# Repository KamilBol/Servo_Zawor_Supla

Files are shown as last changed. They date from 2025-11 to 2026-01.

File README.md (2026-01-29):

# Servo_Zawor_Supla (Wemos Edition)
### Sterownik zaworu C.O. na Wemos D1 Mini + SG90
**Autor:** Kamil Ból ("Bólu")

Projekt sterownika do zaworu kulowego (lub innego elementu C.O.), opartego na serwomechanizmie modelarskim (np. SG90) i mikrokontrolerze Wemos D1 Mini. Układ działa jako element wykonawczy dla systemu SUPLA (lub innej automatyki), reagując na impuls sterujący.

### 🔥 Główne Funkcje (Bólu Soft v3.0):
* **Sterowanie Mikrosekundami:** Pełna płynność i precyzja dla serw SG90/MG90.
* **Ghost Buster:** Algorytm odszumiania pinów (działa stabilnie bez zewnętrznych rezystorów!).
* **Pamięć EEPROM:** Po zaniku prądu sterownik pamięta, gdzie skończył. Zero szarpania przy starcie.
* **Safety Mode:** Jeśli czujnik (kontaktron) ulegnie awarii, system to wykryje i po 10 próbach zresetuje się, zamiast niszczyć zawór.
* **Tryb Serwisowy:** Możliwość kalibracji kątów i odwracania logiki przyciskami - bez podłączania komputera!

---

### 🛠️ Hardware (Co potrzebujesz)
1.  **Wemos D1 Mini** (ESP8266)
2.  **Serwo SG90** (lub MG996R - wymaga zmiany czasów w kodzie)
3.  **Kontaktron** (Czujnik otwarcia/zamknięcia)
4.  **Drugi moduł Supla** (jako wyzwalacz)
5.  Zasilacz 5V (stabilny!)

---

### 🔌 Pinout (Podłączenie)
Szczegółowy schemat znajdziesz w folderze `/doc`.

| PIN Wemos | Funkcja | Opis |
| :--- | :--- | :--- |
| **D1 (GPIO 5)** | **SERWO** | Sygnał PWM (Żółty/Pomarańczowy kabel) |
| **D2 (GPIO 4)** | **TRIGGER** | Impuls 3.3V (HI) z Supli uruchamia ruch |
| **D5 (GPIO 14)** | **CZUJNIK** | Kontaktron (HI 3.3V = Zamknięty) |
| **D4 (GPIO 2)** | **LED** | Wbudowana dioda sygnalizacyjna |
| **D6 (GPIO 12)** | *Serwis (-)* | Zmniejszanie kąta otwarcia |
| **D7 (GPIO 13)** | *Serwis (+)* | Zwiększanie kąta otwarcia |
| **D0 (GPIO 16)** | *Serwis (L)* | Odwracanie logiki czujnika (trzymać 5s) |

---

### 🚀 Jak to działa?
1.  Wemos czeka na impuls **3.3V (HI)** na pinie **D2**.
2.  Po otrzymaniu impulsu sprawdza stan czujnika na **D5**.
3.  Jeśli czujnik pokazuje "Zamknięty" -> Serwo otwiera zawór.
4.  Jeśli czujnik pokazuje "Otwarty" -> Serwo zamyka zawór.
5.  Ruch trwa 5 sekund (płynny start i stop).
6.  Pozycja zapisywana jest w pamięci stałej.

---

### 📜 Licencja
Róbta co chceta (MIT). Kod jest dla ludzi.
https://github.com/KamilBol/Servo_Zawor_Supla/blob/main/3D/Zrzut%20ekranu%202026-01-29%20003321.png?raw=true

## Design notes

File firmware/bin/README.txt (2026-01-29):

===================================  INSTRUKCJA FLASHOWANIA (.BIN)  ======================================
Uruchom ESP8266 Download Tool -> Developer Mode -> ESP8266.

SEKCJA "SPIDownload": [X] Zaznacz "ptaszka" przy ścieżce pliku. [...] Wybierz plik: STEROWNIK_ZAWORU.ino.bin [@] Adres wpisz: 0x00000

PARAMETRY (Wemos D1 Mini):

Crystal Freq: 26M

SPI SPEED: 40MHz

SPI MODE: DIO <-- WAŻNE!

FLASH SIZE: 32Mbit

PODŁĄCZENIE:

COM: Wybierz swój port.

BAUD: 921600 (lub 460800).

AKCJA: Kliknij START. Jak zobaczysz "FINISH", odłącz i podłącz zasilanie. Gotowe. 
=========================================================================

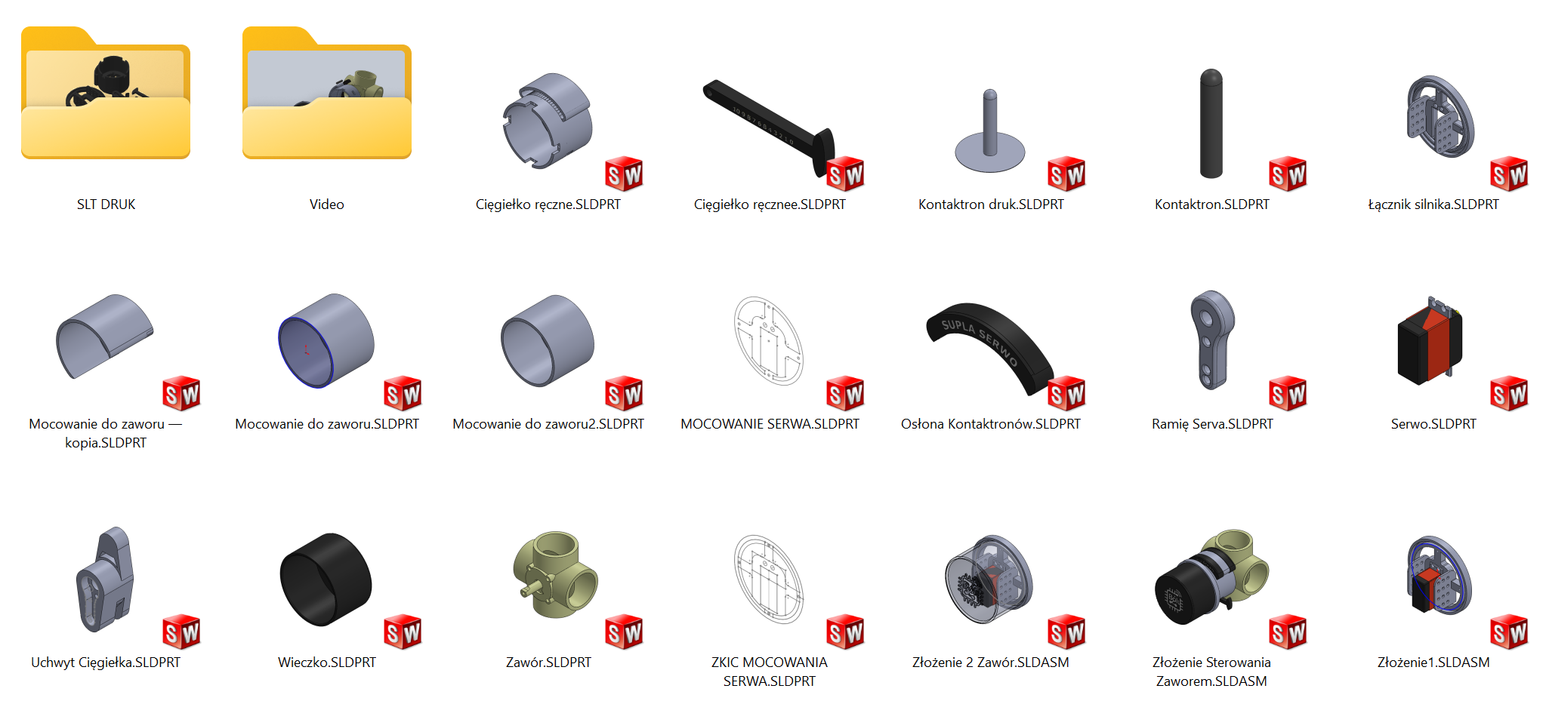
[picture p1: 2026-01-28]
3D/Zrzut ekranu 2026-01-29 003321.png

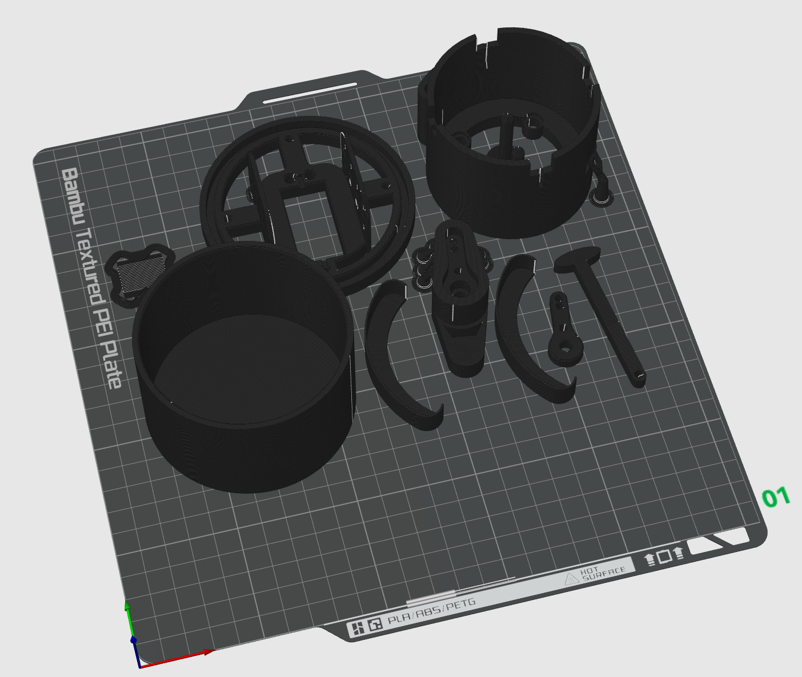
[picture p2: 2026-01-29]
3D/Zrzut ekranu 2026-01-29 011720.png

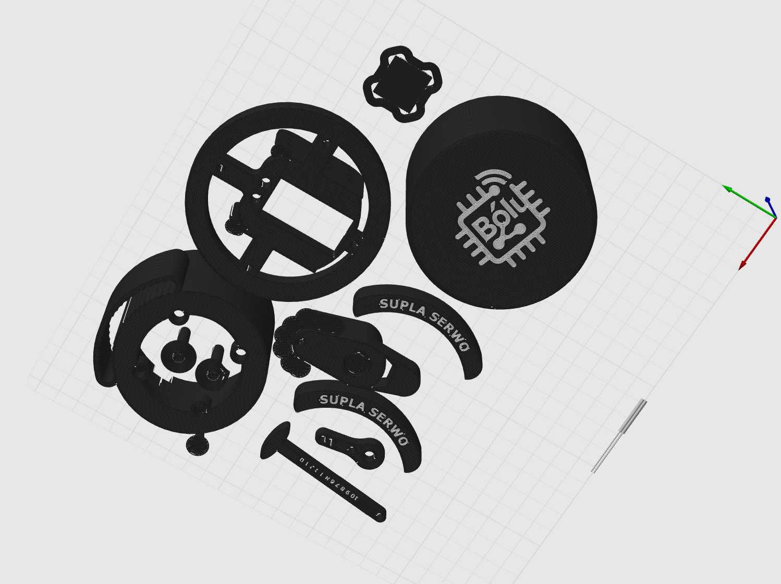
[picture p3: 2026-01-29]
3D/Zrzut ekranu 2026-01-29 011803.png

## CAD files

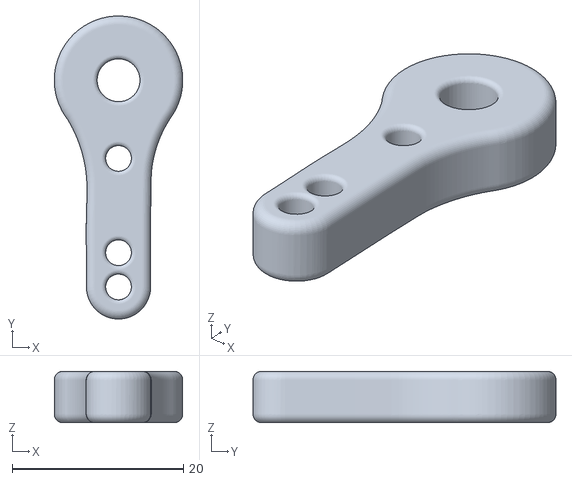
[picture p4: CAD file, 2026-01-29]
3D/7 Ramię Serva.STL
15.0 x 35.4 x 6.00

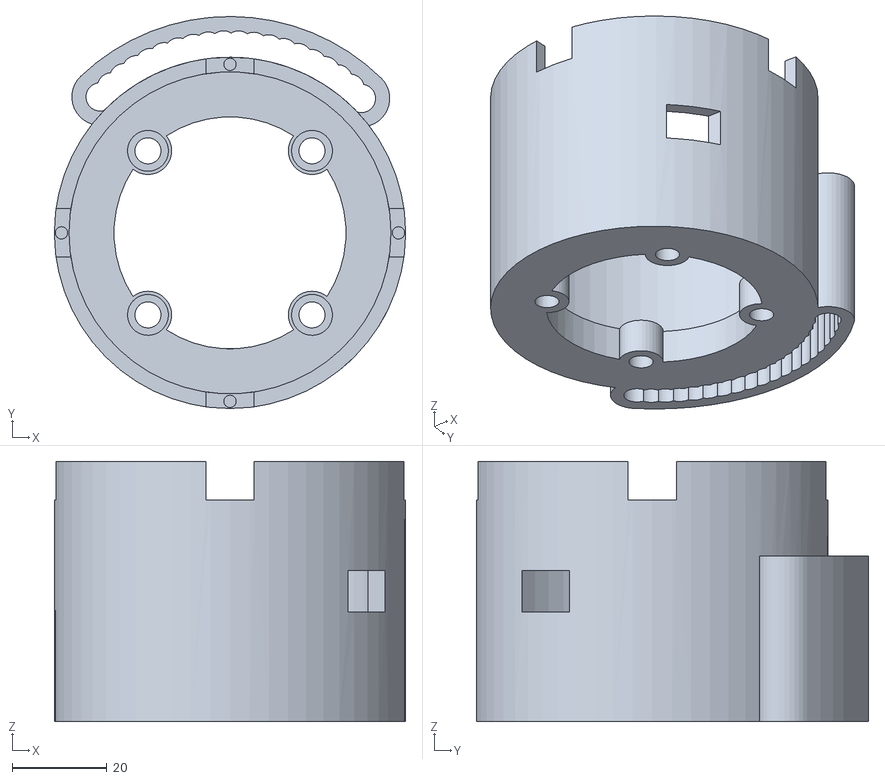
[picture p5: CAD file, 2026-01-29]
3D/1 Cięgiełko ręczne.STL
74.2 x 82.8 x 55.0

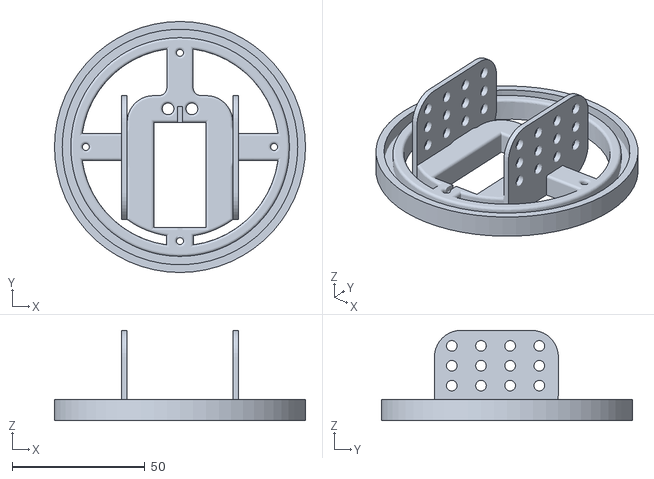
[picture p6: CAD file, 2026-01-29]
3D/6 Łącznik silnika.STL
94.6 x 94.6 x 34.0

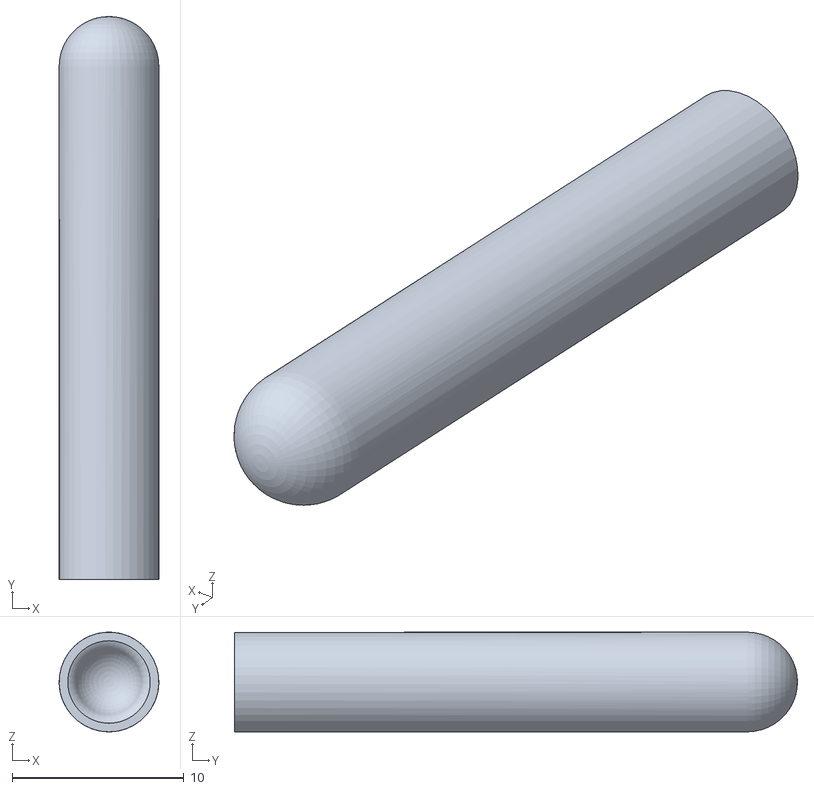
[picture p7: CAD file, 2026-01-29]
3D/4 Kontaktron X2 DRUKINIJ.STL
5.80 x 32.7 x 5.80

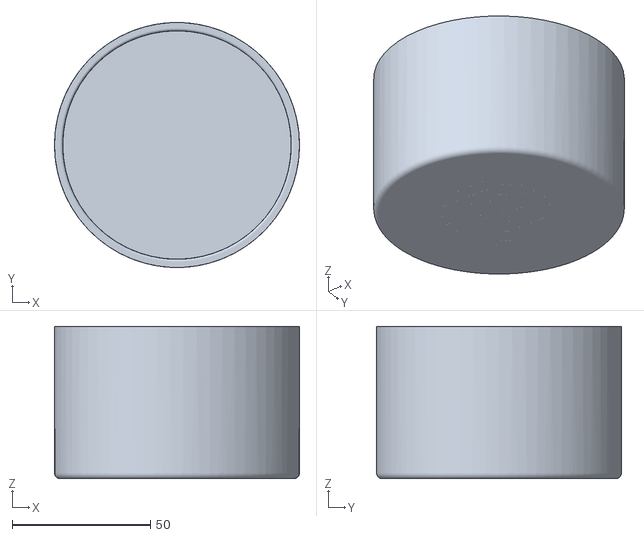
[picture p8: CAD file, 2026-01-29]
3D/8 Wieczko.STL
88.5 x 88.4 x 55.0

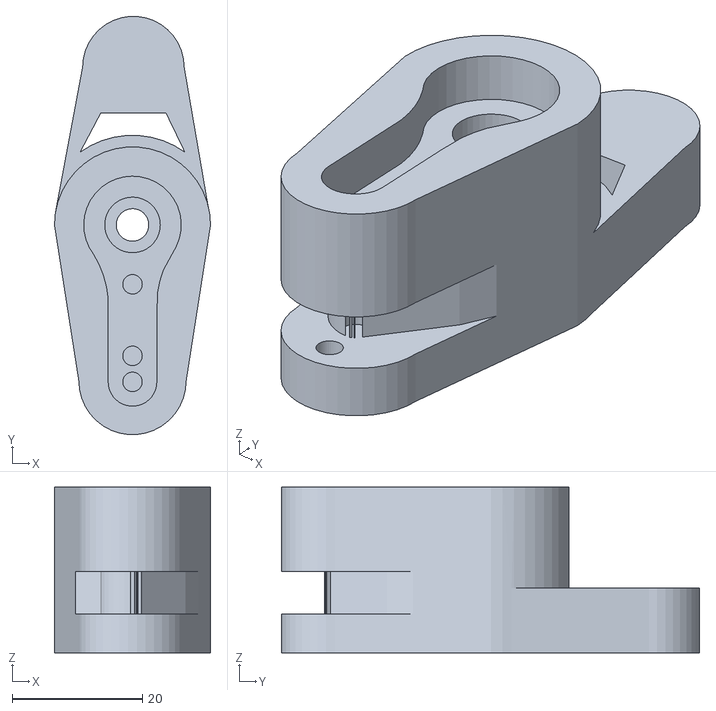
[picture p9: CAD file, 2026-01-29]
3D/2 Uchwyt Cięgiełka.STL
24.0 x 64.3 x 25.5

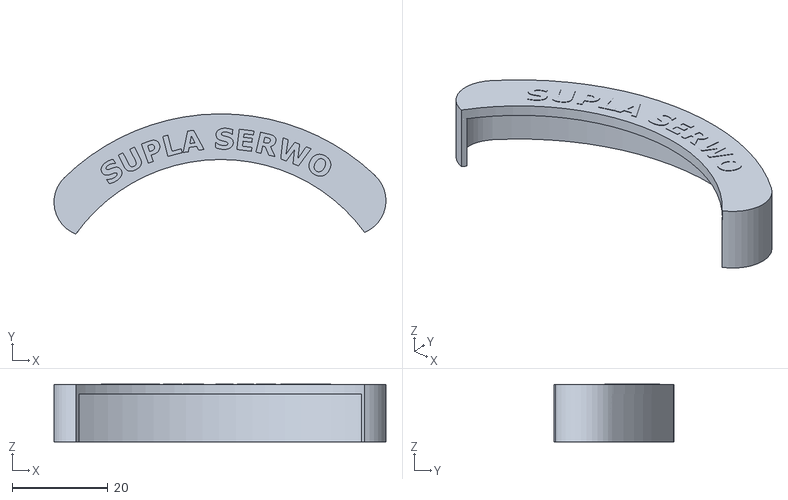
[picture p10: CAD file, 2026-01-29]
3D/5 Osłona Kontaktronów.STL
69.4 x 25.1 x 12.1

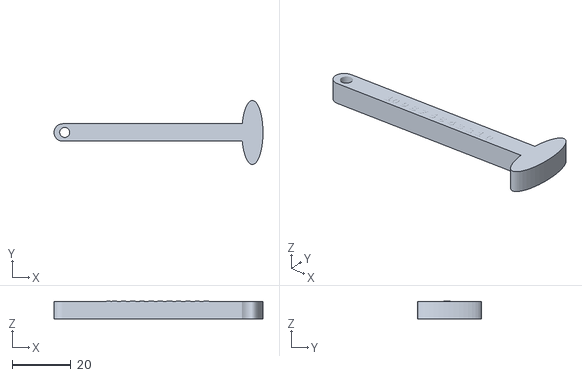
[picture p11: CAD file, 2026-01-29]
3D/3 Cięgiełko ręcznee.STL
71.0 x 21.7 x 6.10

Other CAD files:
3D/Zawór Supla Servo Do druku.gcode.3mf
3D/9 Osłona Kontaktronów.STL

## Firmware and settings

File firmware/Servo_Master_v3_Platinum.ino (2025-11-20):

#include <Arduino.h>
#include <Servo.h>
#include <EEPROM.h>

/*
   ===================================================================================
   PROJEKT: STEROWNIK ZAWORU C.O. - WERSJA PLATINUM (FULL STABILIZACJA)
   AUTOR: KAMIL BÓL ("BÓLU")
   
   POPRAWKA:
   - Zastosowano "Ghost Buster" (odszumianie) również dla pinów serwisowych (D6, D7, D0).
   - Koniec z samoistną zmianą kątów przez zakłócenia.
   
   PINOUT (Wemos D1 Mini):
   - D1 (GPIO 5)  -> Serwo
   - D2 (GPIO 4)  -> Trigger (Start)
   - D5 (GPIO 14) -> Kontaktron (Czujnik)
   - D4 (GPIO 2)  -> LED (Info)
   
   PINY SERWISOWE:
   - D6 (GPIO 12) -> Zmniejsz kąt (-5 st.)
   - D7 (GPIO 13) -> Zwiększ kąt (+5 st.)
   - D0 (GPIO 16) -> Odwróć logikę (trzymaj 5s)
   ===================================================================================
*/

Servo myServo; // Mój silnik

// === MOJE USTAWIENIA KALIBRACJI (SG90) ===
int US_ZAMKNIETY = 600;   // 0 stopni
int US_OTWARTY   = 2400;  // 180 stopni (To zmienna, bo D6/D7 ją zmienia)

const int CZAS_RUCHU_MS = 5000; // Ma być wolno (5s)

// === MOJE PINY ===
const int PIN_SERVO   = 5;  // D1
const int PIN_TRIGGER = 4;  // D2
const int PIN_SENSOR  = 14; // D5
const int PIN_LED     = 2;  // D4 (LED na płytce)

// === MOJE PINY SERWISOWE ===
const int PIN_KALIB_MINUS = 12; // D6
const int PIN_KALIB_PLUS  = 13; // D7
const int PIN_LOGIKA_SWAP = 16; // D0 

// === ADRESY W PAMIĘCI EEPROM ===
const int ADRES_MEM     = 0;  // Tu siedzi pozycja serwa
const int ADRES_KOREKTY = 20; // Tu siedzi korekta kąta
const int ADRES_LOGIKI  = 30; // Tu siedzi odwrócona logika

// === ZMIENNE SYSTEMOWE ===
int aktualneMikrosekundy = 0;       
unsigned long czasOstatniejAkcji = 0;
const int CZAS_COOLDOWN = 2000;     
int licznikBledow = 0;              

// Zmienne serwisowe
int korektaKonta = 0;         
bool logikaOdwrocona = false; 
unsigned long czasTrzymaniaD0 = 0; // Licznik dla przycisku logiki

// ===================================================================================
// === FUNKCJA: GHOST BUSTER (ODSZUMIANIE) ===
// ===================================================================================
// Trik na wiszące kable bez rezystorów. Zwieram do masy i sprawdzam czy sygnał wróci.
bool sprawdzPin(int pin) {
  if (digitalRead(pin) == LOW) return false;
  
  pinMode(pin, OUTPUT); 
  digitalWrite(pin, LOW); 
  delayMicroseconds(10); 
  pinMode(pin, INPUT);   
  
  if (digitalRead(pin) == HIGH) return true; // To prawdziwy prąd
  return false; // To był szum
}

// ===================================================================================
// === FUNKCJA: MRUGANIE (DISCO) ===
// ===================================================================================
void mrugnij(int ile, int szybkosc) {
  for(int i=0; i<ile; i++) {
    digitalWrite(PIN_LED, LOW);  delay(szybkosc);
    digitalWrite(PIN_LED, HIGH); delay(szybkosc);
  }
}

// ===================================================================================
// === FUNKCJA: ZAPIS DO PAMIĘCI ===
// ===================================================================================
void zapiszPamiec(int wartosc) {
  EEPROM.put(ADRES_MEM, wartosc);
  EEPROM.commit();
}

// ===================================================================================
// === FUNKCJA SERWISOWA (D6, D7, D0) - TERAZ STABILNA! ===
// ===================================================================================
void sprawdzTrybSerwisowy() {
  
  // --- 1. KALIBRACJA KĄTA (D6 / D7) ---
  // Używam sprawdzPin zamiast digitalRead, żeby wyeliminować zakłócenia!
  
  // D6 -> ZMNIEJSZ KĄT
  if (sprawdzPin(PIN_KALIB_MINUS)) { 
     delay(100); 
     if (sprawdzPin(PIN_KALIB_MINUS)) { // Podwójne sprawdzenie
        korektaKonta -= 50; // Odejmij ~5 stopni
        US_OTWARTY += -50;  // Zmień zakres
        
        Serial.print("!!! SERWIS D6: Zmniejszam kat. Nowy MAX: "); Serial.println(US_OTWARTY);
        mrugnij(1, 500); // 1 długi błysk
        
        EEPROM.put(ADRES_KOREKTY, korektaKonta); EEPROM.commit();
        delay(1000); 
     }
  }
  
  // D7 -> ZWIĘKSZ KĄT
  if (sprawdzPin(PIN_KALIB_PLUS)) {
     delay(100); 
     if (sprawdzPin(PIN_KALIB_PLUS)) {
        korektaKonta += 50; // Dodaj ~5 stopni
        US_OTWARTY += 50;   
        
        Serial.print("!!! SERWIS D7: Zwiekszam kat. Nowy MAX: "); Serial.println(US_OTWARTY);
        mrugnij(2, 150); // 2 szybkie błyski
        
        EEPROM.put(ADRES_KOREKTY, korektaKonta); EEPROM.commit();
        delay(1000);
     }
  }

  // --- 2. ODWRACANIE LOGIKI (D0 - Trzymaj 5s) ---
  if (sprawdzPin(PIN_LOGIKA_SWAP)) { // Tu też Ghost Buster
    if (czasTrzymaniaD0 == 0) czasTrzymaniaD0 = millis();
    
    // Czy trzymam już 5 sekund?
    if (millis() - czasTrzymaniaD0 > 5000) {
       logikaOdwrocona = !logikaOdwrocona; // Zmień flagę
       
       Serial.print("!!! SERWIS D0: ZMIANA LOGIKI !!! Odwrocona: "); Serial.println(logikaOdwrocona);
       mrugnij(5, 50); // DISCO Potwierdzenie
       
       EEPROM.put(ADRES_LOGIKI, logikaOdwrocona); EEPROM.commit();
       
       czasTrzymaniaD0 = 0; 
       delay(3000); 
    }
  } else {
    czasTrzymaniaD0 = 0;
  }
}

// ===================================================================================
// === FUNKCJA RUCHU ===
// ===================================================================================
void wykonajRuch(int celUS) {
  Serial.println("\n----------------------------------------");
  int startUS = aktualneMikrosekundy;
  
  if (celUS == US_OTWARTY) Serial.println("Decyzja: OTWIERAM");
  else Serial.println("Decyzja: ZAMYKAM");
  
  Serial.print("   Start: "); Serial.print(startUS);
  Serial.print(" -> Cel: "); Serial.println(celUS);

  // Jeśli każę mu jechać tam gdzie jest -> Blokada
  if (abs(celUS - startUS) < 50) {
    Serial.println("!!! BLOKADA: Juz tam jestem.");
    return;
  }

  int kroki = abs(celUS - startUS) / 10; 
  if (kroki == 0) kroki = 1;
  int opoznienie = CZAS_RUCHU_MS / kroki;

  // START
  Serial.println("   [Silnik] Start...");
  myServo.writeMicroseconds(startUS); 
  myServo.attach(PIN_SERVO);
  delay(200); 

  // JAZDA
  if (startUS < celUS) {
    for (int i = startUS; i <= celUS; i += 10) {
      myServo.writeMicroseconds(i); delay(opoznienie); yield();
    }
  } else {
    for (int i = startUS; i >= celUS; i -= 10) {
      myServo.writeMicroseconds(i); delay(opoznienie); yield();
    }
  }
  
  // Dociągnij i Zapisz
  myServo.writeMicroseconds(celUS);
  delay(opoznienie);
  
  Serial.println("   [Silnik] Stop. Zapis EEPROM.");
  aktualneMikrosekundy = celUS;
  zapiszPamiec(aktualneMikrosekundy); 
  
  delay(500); 
  myServo.detach();
  licznikBledow = 0; // Reset błędów, bo poszło gładko
  Serial.println("--- KONIEC ---");
}

// ===================================================================================
// === SETUP ===
// ===================================================================================
void setup() {
  Serial.begin(115200);
  EEPROM.begin(512); 
  delay(100);
  Serial.println("\n\n=== WITAJ KAMILU. STABILIZACJA PEŁNA! ===");

  // Ustawiam piny
  pinMode(PIN_LED, OUTPUT); digitalWrite(PIN_LED, HIGH); 
  pinMode(PIN_SERVO, OUTPUT); digitalWrite(PIN_SERVO, LOW);
  pinMode(PIN_TRIGGER, INPUT);
  pinMode(PIN_SENSOR, INPUT);
  
  // Piny serwisowe
  pinMode(PIN_KALIB_MINUS, INPUT);
  pinMode(PIN_KALIB_PLUS, INPUT);
  pinMode(PIN_LOGIKA_SWAP, INPUT); 

  // --- WCZYTANIE USTAWIEŃ SERWISOWYCH ---
  EEPROM.get(ADRES_KOREKTY, korektaKonta);
  if (korektaKonta < -1000 || korektaKonta > 1000) korektaKonta = 0; 
  US_OTWARTY += korektaKonta; // Aplikuję korektę
  Serial.print("[SERWIS] Korekta kata: "); Serial.println(korektaKonta);

  EEPROM.get(ADRES_LOGIKI, logikaOdwrocona);
  if (logikaOdwrocona != 0 && logikaOdwrocona != 1) logikaOdwrocona = false;
  Serial.print("[SERWIS] Logika odwrocona: "); Serial.println(logikaOdwrocona);

  // --- WCZYTANIE POZYCJI SERWA ---
  int pamiec;
  EEPROM.get(ADRES_MEM, pamiec);
  
  if (pamiec < 500 || pamiec > 3000) {
    Serial.println("[PAMIEC] Pusta. Ustawiam wg czujnika.");
    
    bool rawSensor = sprawdzPin(PIN_SENSOR);
    bool logicSensor = (logikaOdwrocona) ? !rawSensor : rawSensor;

    if (logicSensor) pamiec = US_ZAMKNIETY;
    else pamiec = US_OTWARTY;
    zapiszPamiec(pamiec); 
  }
  
  aktualneMikrosekundy = pamiec;
  Serial.print("Pozycja startowa: "); Serial.println(aktualneMikrosekundy);
  
  Serial.println("Czekam 10s na stabilizację...");
  for(int i=0; i<10; i++) { delay(1000); Serial.print("."); }
  Serial.println("\nGOTOWY.");

  // LED START
  if (aktualneMikrosekundy == US_ZAMKNIETY) {
    mrugnij(6, 100); // 6x Zamknięty
  } else {
    mrugnij(3, 100); // 3x Otwarty
  }
  
  licznikBledow = 0; 
}

// ===================================================================================
// === LOOP ===
// ===================================================================================
void loop() {
  
  // 1. SPRAWDŹ SERWIS (Teraz stabilnie przez Ghost Buster!)
  sprawdzTrybSerwisowy();

  // 2. NORMALNA PRACA
  bool trigger = sprawdzPin(PIN_TRIGGER);

  if (trigger) {
    if (millis() - czasOstatniejAkcji > CZAS_COOLDOWN) {
      
      Serial.println("\n!!! DOSTAŁEM IMPULS NA D2 !!!");
      
      // Sygnalizacja LED (1s)
      Serial.println("LED: Potwierdzam odbiór.");
      digitalWrite(PIN_LED, LOW); delay(1000); digitalWrite(PIN_LED, HIGH);
      
      // ODCZYT D5 (Z UWZGLĘDNIENIEM LOGIKI)
      bool sensorFizyczny = sprawdzPin(PIN_SENSOR);
      bool sensorLogiczny = (logikaOdwrocona) ? !sensorFizyczny : sensorFizyczny;
      
      int celUS;
      
      if (sensorLogiczny) {
        Serial.println("Czujnik D5: ZAMKNIETY -> Cel: OTWARCIE");
        celUS = US_OTWARTY; 
      } else {
        Serial.println("Czujnik D5: OTWARTY -> Cel: ZAMKNIECIE");
        celUS = US_ZAMKNIETY;
      }
      
      // WALIDACJA
      if (abs(aktualneMikrosekundy - celUS) < 100) {
        
        // Błąd logiczny (czujnik kłamie)
        licznikBledow++;
        Serial.print("!!! BŁĄD LOGICZNY !!! Licznik: ");
        Serial.print(licznikBledow); Serial.println("/10");
        
        mrugnij(2, 200); // Błąd
        
        if (licznikBledow >= 10) {
          Serial.println(">>> ZA DUŻO BŁĘDÓW. RESTART... <<<");
          delay(1000); ESP.restart();
        }
        
      } else {
        // Wszystko OK
        mrugnij(2, 80); // Potwierdzenie
        wykonajRuch(celUS);
      }
      
      czasOstatniejAkcji = millis();
    }
  }
  delay(50);
}

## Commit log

2025-11-19 Add ESP01S valve control firmware
    1 Wersja
2025-11-19 Create Servo_Zawor_Supla_v1.0(Tutaj bedzie skompilowana Binka kodu).bin
    pusta binka
2025-11-19 Create schematics
2025-11-19 Add initial RELEASES.md for Servo_Zawor_Supla
2025-11-19 Refactor ESP01S valve control code
    Poprawka dotyczy zachowania po restarcie. Gdy esp01 się zrestartuje dowie się gdzie jest zawór ale pozostanie bez ruchu.
2025-11-19 Add wiring schematic for four-way valve connection
    Added a detailed wiring diagram for a four-way valve connection, including power supply requirements and contactor connections.
2025-11-20 Add service and configuration manual for 'SERVO MASTER'
2025-11-20 Enhance servo control with EEPROM and noise reduction
    Added EEPROM support and improved stability for the servo control system. Implemented ghost buster noise reduction for service pins and added calibration settings.
2025-11-20 Add Servo_Master_v3_Platinum.ino file
2026-01-28 Revise service instructions and add Supla configuration
    Updated the service and configuration instructions for the 'SERVO MASTER' controller, including new version details and added instructions for Supla integration.
